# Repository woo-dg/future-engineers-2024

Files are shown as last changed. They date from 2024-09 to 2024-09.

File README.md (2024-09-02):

WRO Future Engineers Team SD Engineering Documentation
====

This repository contains engineering materials of a self-driven vehicle model participating in the WRO Future Engineers competition in the 2023 season. More information on each subcomponent of the robot is placed in the README.md files in each folder.

## Content
* `build` contains documentation about our chassis and material choice
* `electrical` contains schematic diagrams demonstrating the connections between different electromechanical components. It also includes the available datasheets for the aforementioned components, and it also has a markdown file explaining the reasoning for each component.
* `photos` contains two folders where one contains the team photos and the other contains the robot photos
* `src` contains the code of control software for all components that were programmed to participate in the competition
* `strategy` contains documentation and diagrams explaining our approach to the problem
* `video` contains the video.md file with the link to a video where the driving demonstration exists

## Rubric Requirements
* `Mobility Management` is found in `build` and  `electrical` 
* `Power and Sense Management` is found in `electrical`
* `Obstacle Management` is found in `strategy` and `src`
* `Pictures - Team and Vehicle` is found in `photos`
* `Performance Videos` is found in `video`
* `Engineering Factor` is found in `build` and `README`

### Who We Are
Team SD consits of 2 of high school students who aim to be leaders in the future of autonomous vehicles. By taking the initiative to take part in the WRO Future Engineers challenge, we hope to gain experience in this field of engineering and problem-solving. We have been exposed to many robotic and logical challenges through Zebra Robotics, where we participated in many problems, such as WRO Robomissions, FIRST LEGO League, and VEX Robotics Competition. Our goals for this season are the following:
- Gain knowledge in the field of autonomous vehicles
- Expose ourselves to the nuances of software organization (i.e. Github)
- Become proficient in the skills regarding electronic components
- Learn how to coordinate and work as a team to solve the problem with innovation and creativity

### Our Robot & Iterations
Our team has designed a four-wheel rear-driver autonomous vehicle to complete the 2024 WRO Future Engineers challenge. When making our robot, we wanted to be able to rapidly iterate and make changes whenever they were needed. To accomplish this, our chassis and frame are designed on SolidWorks and Fusion 360 CAD Software and were printed using PLA filament on Anycubic Kobra 2 3D printers. Our current robot is a small and compact vehicle causing it to be highly maneuverable, allowing us to avoid obstacles effortlessly. This vehicle is powered by 160rpm 12V Gear Box DC motors, allowing us to keep a compact and lightweight robot. To steer this chassis, we are using the MG90 Arduino Servo, which has an ample amount of torque and strength. This allows us to make sharp turns whenever needed.
Prior to making this robot, our team went through various different iterations and prototypes where we learnt many lessons about what our optimal robot should consist of. These lessons are the following:
- Be small and compact
- Effectively use sensors to identify our location and our ideal path
- Speed is not the first priority for this challenges
- Maneuverability is key to solving the obstacle challenge

One of these was a larger robot with the usage of many more sensors and parts. However, its large nature caused it to be difficult to maneuver and control. All of our efforts were in vain as we faced many hardships and problems when trying to program that robot. Our robot’s turning radius was too large, and it was unable to maneuver around the obstacles while our sensors were placed inconveniently and were unable to correctly and quickly construct an efficient path for our robot to take. We realized that many parts of our robot were unnecessary, especially the sheer size of it, and therefore we decided to do a complete redesign which led to our final robot design. A summary of the reasons for our redesign can be found below:

| | Pros | Cons |
| - | ---| ---|
| Old Robot | <ul><li>Allows for the attachment of larger sensors</li><li>Faster robot due to the larger, more powerful motors</li></ul> | <ul><li>Bad maneuverability due to size, causing a larger turning radius</li><li>Excessive use of unnecessary sensors</li><li>Not enough ports due to the sheer number of sensors</li></ul> |
| New Robot | <ul><li>Smaller and more compact</li><li>Better maneuverability and sharper turning radius</li><li>More effective use of sensors and gets rid of any unnecessary parts</li></ul> | <ul><li>Slower speed due to less powerful motors</li><li>Restrictions to the size of sensors and parts we can use</li></ul> |

### Electrical Components
Our chassis is controlled by the Arduino Nano microcontroller, which gets information from various sensors and uses said information to control the motors using an L298N motor controller board. The sensors that we are using for our vehicle are the following:

- Pixycam 2.1
- TCS34725 RGB Sensor
- GP2Y0A02YK0F IR Range Sensor (x 2)
- L3G4200D 3-Axis Gyro

We use the Pixycam 2.1 to identify the locations of the obstacles and effectively avoid them. The TCS34725 RGB sensor tells the microcontroller when it reaches a corner. Both IR sensors are used to detect the walls on the side and on the front. Finally, we use the L3G4200D gyro to know which direction we are facing. More information about our robot’s electrical components can be found in the README file in the electrical folder.

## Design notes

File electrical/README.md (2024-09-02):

Electrical
====

This directory consists of schematic diagrams demonstrating the connections between different components as well as datasheets for the components. It also consists of the reasoning behind the choice of components.

## Parts Explanation

| Part Name | Explanation | Image | Datasheet |
| --- | --- | --- | --- |
| 1.5V Rechargeable Lithium Ion Battery | We are using this battery to power all of our electronics as it is compact and easy to get. They are also efficient for us as they are rechargeable and do not have to be replaced. |  | [Battery Info](https://drive.google.com/file/d/1sINeE1pQsb4mYleB1K3RjQIi_3ilcRdc/view?usp=sharing) |
| DC 6V 25SG-2418BL 160RPM | We are using this specific motor to drive the robot as it contains a gearbox that can reach a maximum speed of 160RPM. The compact size of these motors, coupled with a high RPM, allowed for our smaller compact design to succeed. |  | [DC Motor Info](https://drive.google.com/file/d/1ovx4JvY0TAlGeaWuEGIg9i7RbAIlBQif/view?usp=drive_link) |
| CJMCU34725 TCS34725 RGB Light Color Sensor | By using this RGB color sensor, our robot can accurately detect the blue and orange lines at the mat's corners. This capability enables us to monitor the number of laps completed and ensures the robot makes precise turns when needed. |  | [Color Sensor Info](https://www.waveshare.com/w/upload/b/bb/TCS34725_Color_Sensor_user_manual_en.pdf) |
| Arduino Nano |To process sensor data and make real-time decisions, we are utilizing the Arduino Nano, programmed through the Arduino IDE. This board is user-friendly, with a wide range of readily available libraries. It features 14 digital input/output pins, allowing us to connect various devices, and eight analog pins, two of which are dedicated to I2C communication. | | [Arduino Nano Info](https://www.arduino.cc/en/uploads/Main/ArduinoNanoManual23.pdf) |
| ES08MA Metal Analog Servo | To steer our vehicle, we use a servo motor with a torque of 2.0 kilogram-force centimeters and a speed of 0.10 sec/60°. Given the substantial torque required for steering, this motor offers ample power for our needs. Additionally, its quick response time enables us to execute sharp turns with precision. |  | [Servo Info](https://m.media-amazon.com/images/I/61ZU3A84tYS._AC_SL1000_.jpg) |
| GP2Y0A02YK0F IR Range Sensor | The IR sensors deliver information about the distance to the walls at a fast rate. These sensors accurately detect distances ranging from 20 to 150 cm. We use one sensor to gauge how close the robot is to any wall in front, while the other two help the robot maintain a centered position on the track by following the walls on either side. |  | [GP2Y0A02YK0F IR Range Sensor Info](https://cdn.robotshop.com/media/d/dem/rb-dem-02/pdf/datasheet-gp2y0a02yk0f.pdf) |
| L3G4200D Triple Axis Gyro Angular Velocity Sensor Module |We use a gyro angular velocity sensor to determine our vehicle's angular direction and precisely measure the change in angle during each turn. For accurate angle measurements, we integrate the yaw angular velocity after calibrating the gyro, allowing us to determine the robot's angle relative to its starting position. |  | [Gyro Info](https://www.elecrow.com/download/L3G4200_AN3393.pdf) |
| PixyCam Pixy 2.1 Robot Vision Image Sensor | Since the Arduino Nano lacks sufficient computing power for image processing, we offload this task to the Pixy 2.1 camera. This camera efficiently provides the microcontroller with the necessary data, enabling the robot to plan and follow an optimal path. |  | [Pixy 2.1 Info](https://docs.pixycam.com/wiki/doku.php?id=wiki:v2:start) |

## Parts Bill Of Materials (BOM)
| Part Name | Quantity |
| ---| --- |
| 1.5V Rechargeable Lithium Ion Battery | 4 |
| DC 6V Micro Gear Box Speed Reduction Motor, 160RPM | 1 |
| CJMCU34725 TCS34725 RGB Light Color Sensor | 1 |
| Arduino Nano | 1 |
| ES08MA Metal Analog Servo | 1 |
| GP2Y0A02YK0F IR Range Sensor | 3 |
| L3G4200D Triple Axis Gyro Angular Velocity Sensor Module | 1 |
| PixyCam Pixy 2.1 Robot Vision Image Sensor | 1 |

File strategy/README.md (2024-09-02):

Strategy
====

This directory consists of an explanation and diagrams of our strategy for both the open and obstacle rounds.

## Open Challenge Strategy

In the open challenge, the only variations to the field are the size of the interior walls. To adapt to these changes, we employ IR distance sensors to measure the distance from the walls. With multiple sensors, the robot can accurately calculate its distance from the surrounding walls, enabling it to correct its course and maintain a parallel trajectory. The robot will know when to turn when the RGB sensor detects the colored lines at the corners. This also allows us to track the number of laps completed, ensuring we know when to finish. 

| Straight Movement | Turning |
| --- | --- |
|  |  |

| Open Challenge Flowchart |
| ------------------------ |
|  |

## Obstacle Challenge Strategy

Our strategy for the obstacle challenge is to maintain the closest detected color on the designated side of the robot. This is achieved by monitoring the x-position of objects identified by the camera and adjusting the steering accordingly to ensure that the object remains on the correct side. The turning and stopping mechanisms will utilize the same logic that was successfully implemented in the open challenge.

To optimize our steering adjustments, we employ a proportional control loop, which will allow for precise maneuvering as the robot encounters obstacles. This approach ensures that our movements are both accurate and responsive to the environment.

| Obstacle Challenge Simple Approach |
| ---------------------------------- |
|  |

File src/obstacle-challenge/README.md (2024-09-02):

## Obstacle Challenge Code Explanation

For our obstacle challenge, we use a combination of sensors, including an RGB sensor, IR sensors, a gyro sensor, and a Pixy2 camera. These sensors help the robot navigate the course, avoid obstacles, and execute precise turns. Our code is divided into two main parts: normal navigation and obstacle detection logic. Additionally, we have parking logic to ensure the robot parks correctly within the boundaries.

## Normal Navigation: 
The robot starts by using the RGB sensor, IR sensors, and gyro to maintain a straight path and avoid obstacles. The Pixy2 camera identifies objects and assists with steering adjustments. The Pixy2 camera detects blocks in the robot’s path. If a block is close enough (i.e., its y-coordinate is greater than 35), the robot stores this block as the current target:

`if (pixy.ccc.numBlocks) {
    sig = pixy.ccc.blocks[0].m_signature;
    x = pixy.ccc.blocks[0].m_x;
    y = pixy.ccc.blocks[0].m_y;
    if (sig == 1 && !p) {
        dG = 0;
        if (y > 35) {
            t = millis();
            pr = 1;
            if (x > 70) {
                dR = 75;
            }
        } else if (x < 70) {
            dR = 0;
        }
    }
}` . 

Based on the block’s position and color, the robot adjusts its steering to follow the block closely. This helps the robot maintain a path that avoids obstacles and keeps it on course.

## Wall Following:
When no blocks are detected or when the robot needs to avoid obstacles on its sides, it uses IR sensors for wall following. The robot measures the distance to the walls on its left and right and adjusts its course accordingly:
`if (bl) {
    if (distL < 30 && distR > 30) {
        dD = 30;
    } else if (distR < 30 && distL > 30) {
        dD = -30;
    } else {
        dD = 0;
    }
} else if (o) {
    if (distR < 30 && distL > 30) {
        dD = 20;
    } else if (distL < 30 and distR > 30) {
        dD = -20;
    } else {
        dD = 0;
    }
}` . 

The robot also checks for obstacles directly in front. If it detects something too close, it stops and backs up slightly before continuing. This prevents crashes and allows the robot to navigate around unexpected obstacles.

## Turning Logic 
When the robot approaches a corner and detects the designated color (either orange or blue), it moves forward until it sees the wall. Once the wall is detected and the color is still in view, the robot begins its turning maneuver using the gyro sensor to ensure a precise turn:
`dA += 89;
myservo.write(35);
move_str(false, 100, 1600);
myservo.write(85);`. 

The robot carefully checks its surroundings and only turns after confirming both the presence of the wall and the designated color. This helps the robot avoid premature turns and ensures that it follows the intended path accurately.

If the robot reaches a point where it needs to make a 180-degree turn (reverse lap), it uses the gyro to rotate until it’s aligned with the new direction:
`
dA = -783;
bl = true;
o = false;`

This code adjusts the robot’s internal angle tracking, ensuring it’s ready to continue in the opposite direction after the turn.

## Parking Logic:
After completing three laps, the robot enters the parking phase. It uses the Pixy2 camera to detect nearby objects and adjust its final position. Depending on whether it's in left or right mode, the robot makes slight adjustments to its steering based on the detected signature. If it sees a close block, it fine-tunes its position by setting the servo to a specific angle—either 50 or 120 degrees—depending on the direction. The robot then stops the motor, pauses briefly, and powers up slightly to hold its position, finally entering a prolonged delay to ensure it stays parked securely within the boundaries.
`   else if (p== true){
    if (bl == true){
      if (sig == 1||sig == 2){
        dR =75;
      }
      else if (sig == 3){
        if (y>65){
          myservo.write(50);
          analogWrite(mlp,0);
          digitalWrite(mld,true);
          delay(500);
          analogWrite(mlp,255);
          delay(1000000);
        }
      }
    }
    if (o == true){
      if (sig == 1||sig == 2){
        dG =75;
      }
      else if (sig == 3){
        if (y>65){
          myservo.write(120);
          analogWrite(mlp,0);
          digitalWrite(mld,true);
          delay(500);
          analogWrite(mlp,255);
          delay(1000000);
        }
      }
    }
  }
`.

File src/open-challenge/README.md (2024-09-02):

## Open Challenge Code

In our open challenge approach, we focus on utilizing gyro and infrared (IR) sensors to maintain a precise navigation path. The robot continuously reads sensor data to make real-time adjustments, ensuring it stays on course.

## Gyro-Based Steering:
Before the robot reaches the first corner, it relies on the gyro sensor to maintain a straight path, as it doesn't yet have a fixed directional reference. The robot computes the steering adjustment by mapping the difference between the current angle and the desired target angle:
`str = map(mpu.getAngleZ() - dA, 30, -30, 40, 130);
if (str > 130) {
    str = 130;
} else if (str < 40) {
    str = 40;
}
myservo.write(str);  // Adjust steering` . 

This code continuously updates the servo position, ensuring that the robot corrects any drift from its intended path by adjusting the steering angle.

## Color-Based Direction Setting:
As the robot navigates, it needs to establish and maintain its direction. We use an RGB color sensor to detect specific colors on the track, which helps the robot determine its heading. If the direction isn't set, it assigns the current color as the reference:

`if (lux < 6 && r < 10) {
    if (o == false) {
        dA = dA + 90;
        bl = true;
        bc++;
        while (mpu.getAngleZ() < dA - 15) {
            mpu.update();
            myservo.write(115);
            analogWrite(mlp, 0);
            digitalWrite(mld, true);
        }
    }
}` . 

This ensures the robot is aligned with the track's color cues, setting a baseline for subsequent maneuvers.

## Corner Detection and Handling:
The robot’s cornering logic activates when it detects a change in color, indicating a corner or junction. The system checks if the color matches the established direction and if sufficient time has passed since the last turn. If these conditions are met, the robot adjusts its target angle and prepares to execute a turn:
`if (lux < 6 && r > 15) {
    if (bl == false) {
        dA = dA - 90;
        o = true;
        oc++;
        while (mpu.getAngleZ() > dA + 15) {
            mpu.update();
            myservo.write(55);
            analogWrite(mlp, 0);
            digitalWrite(mld, true);
        }
    }
}`. 

This code allows the robot to make precise turns based on real-time sensor data, ensuring it navigates corners accurately.

## Wall Following:
In tight corridors or when close to walls, the robot employs a wall-following algorithm to maintain a safe distance. The IR sensors measure the distance to the nearest wall, and if the robot gets too close, it adjusts its course to steer away:
`if (bl) {
    mpu.update();
    str = map(mpu.getAngleZ() - dA, 30, -30, 40, 130);
    myservo.write(str);
    distR = sensorR.distance();
    if (distR > 35) {
        myservo.write(75);
    } else if (distR < 25) {
        myservo.write(95);
    }
}
`. 

This block ensures that the robot maintains an optimal distance from the wall by making fine adjustments to its steering, thus avoiding collisions.

## Final Control Adjustments:
Throughout its run, the robot continuously monitors its surroundings and adjusts both its steering and speed to stay on track. The system is designed to avoid abrupt movements, maintaining smooth and controlled navigation until it reaches the end of its path.

By integrating gyro stabilization, color-based direction setting, corner detection, and wall following, the robot effectively navigates the course with precision and adaptability, responding dynamically to its environment.

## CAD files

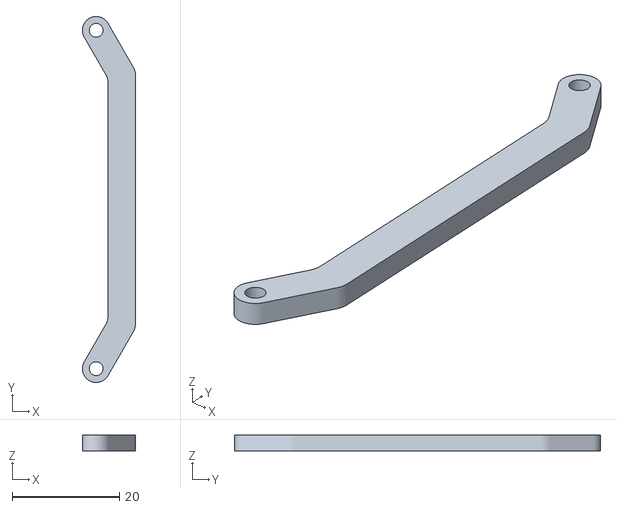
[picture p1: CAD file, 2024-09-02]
build/models/steer-shaft.stl
9.95 x 68.4 x 2.90

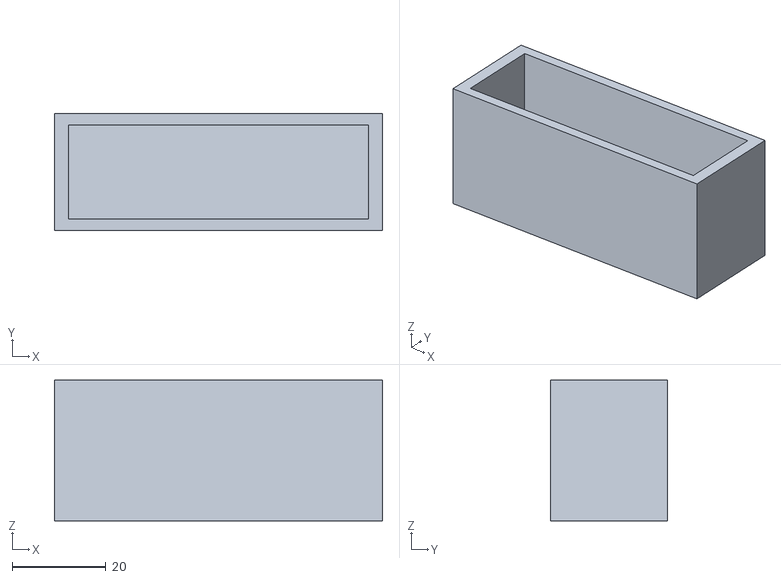
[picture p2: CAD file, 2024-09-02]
build/models/battery-holder.stl
70.0 x 25.0 x 30.0

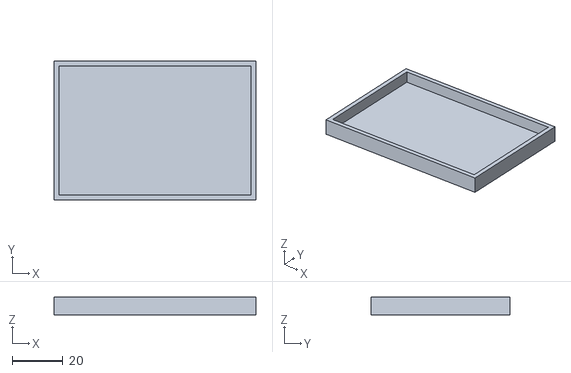
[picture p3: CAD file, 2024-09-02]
build/models/circuit-holder.stl
80.0 x 55.0 x 7.00

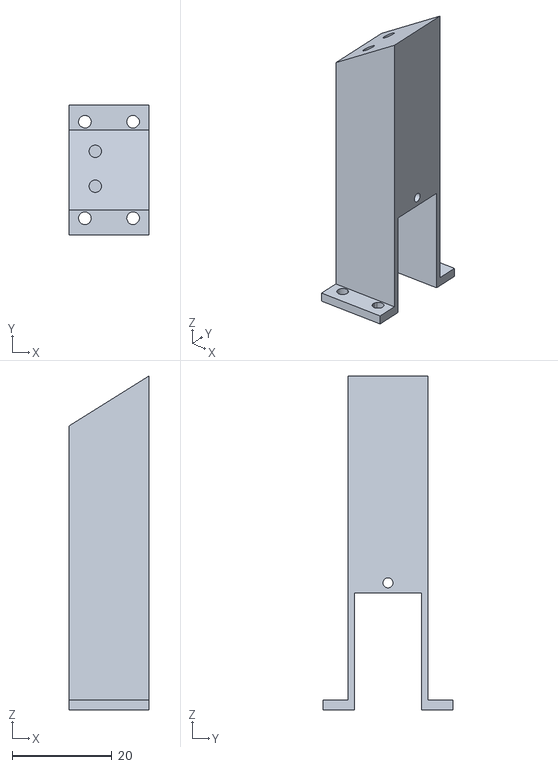
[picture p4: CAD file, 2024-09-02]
build/models/servo (1).stl
16.0 x 26.0 x 67.0

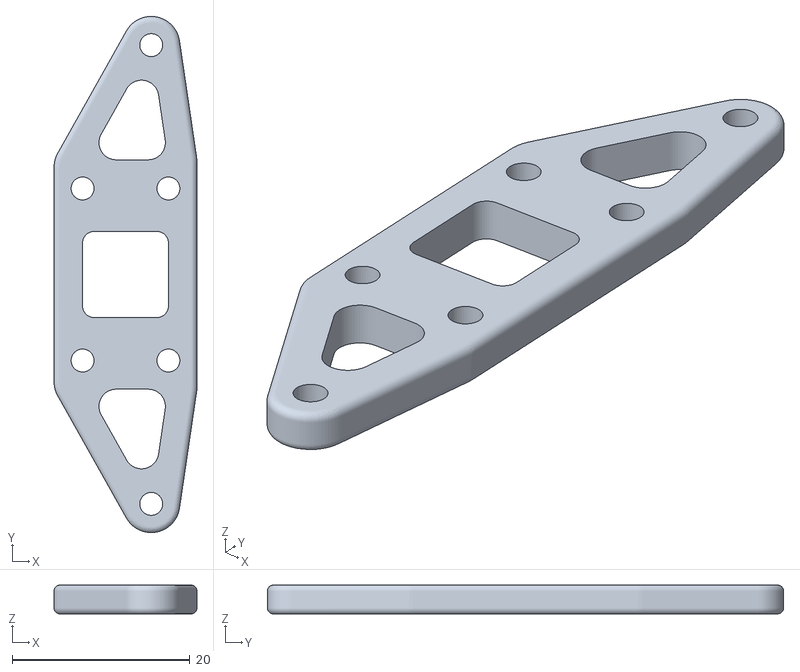
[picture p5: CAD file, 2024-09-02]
build/models/steering-plate.stl
16.1 x 58.1 x 3.23

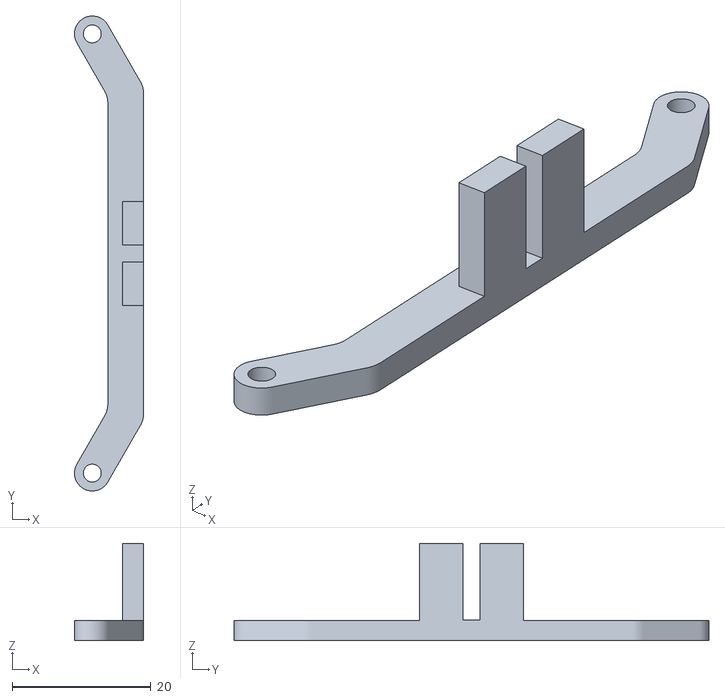
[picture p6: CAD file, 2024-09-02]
build/models/shaft.stl
9.95 x 68.4 x 14.0

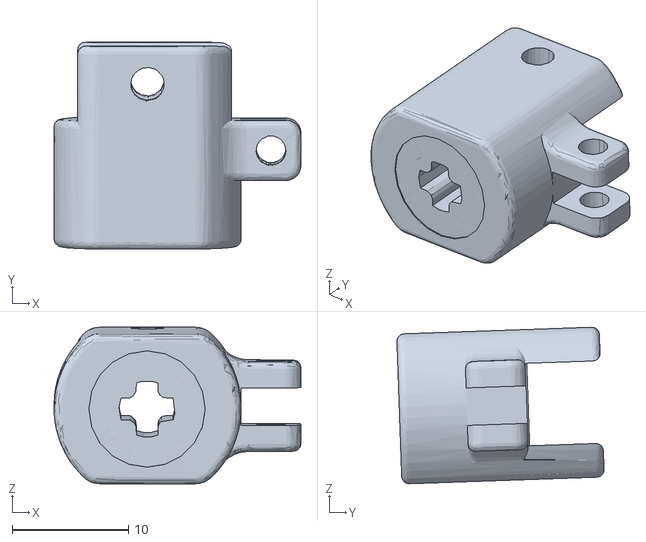
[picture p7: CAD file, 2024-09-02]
build/models/wheel-mount.stl
21.2 x 17.8 x 13.5

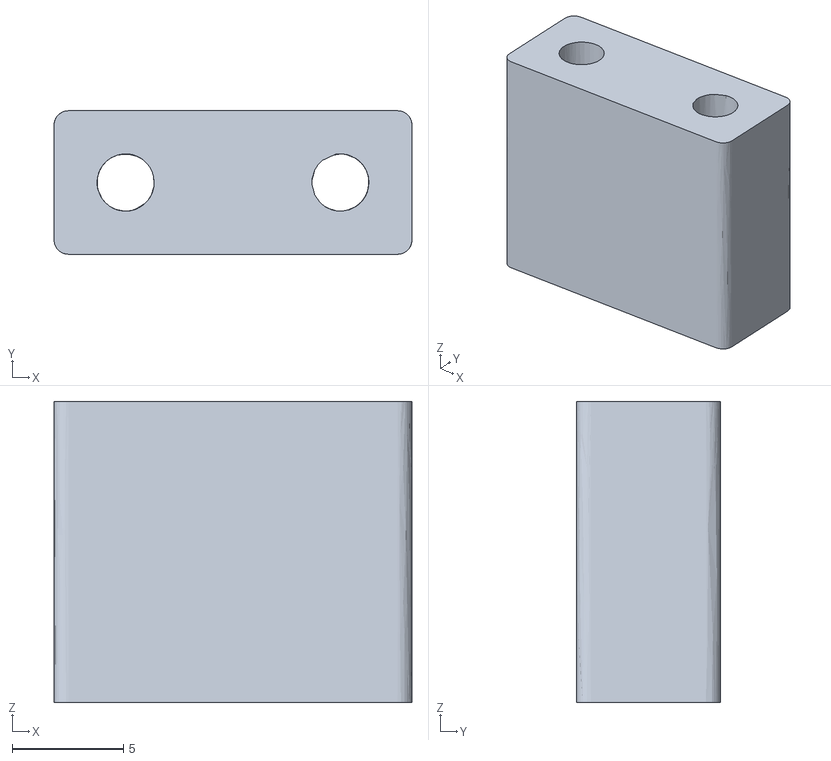
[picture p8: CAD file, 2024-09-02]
build/models/steering-holder.stl
16.1 x 6.45 x 13.5

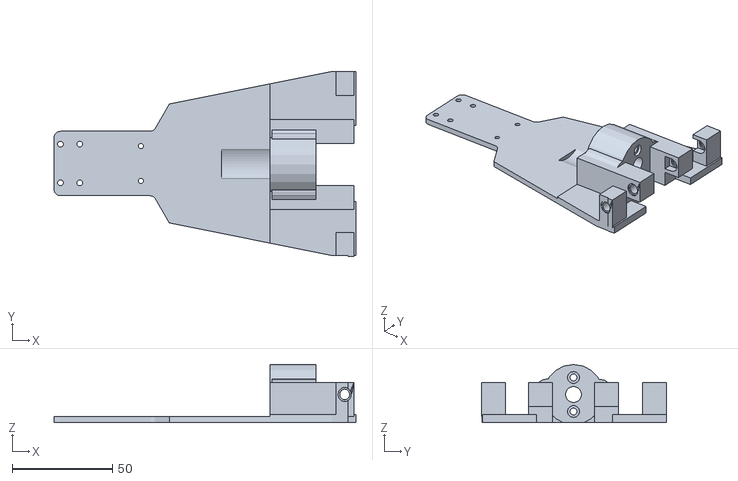
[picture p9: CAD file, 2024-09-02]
build/models/chassis.stl
151.0 x 92.5 x 29.0

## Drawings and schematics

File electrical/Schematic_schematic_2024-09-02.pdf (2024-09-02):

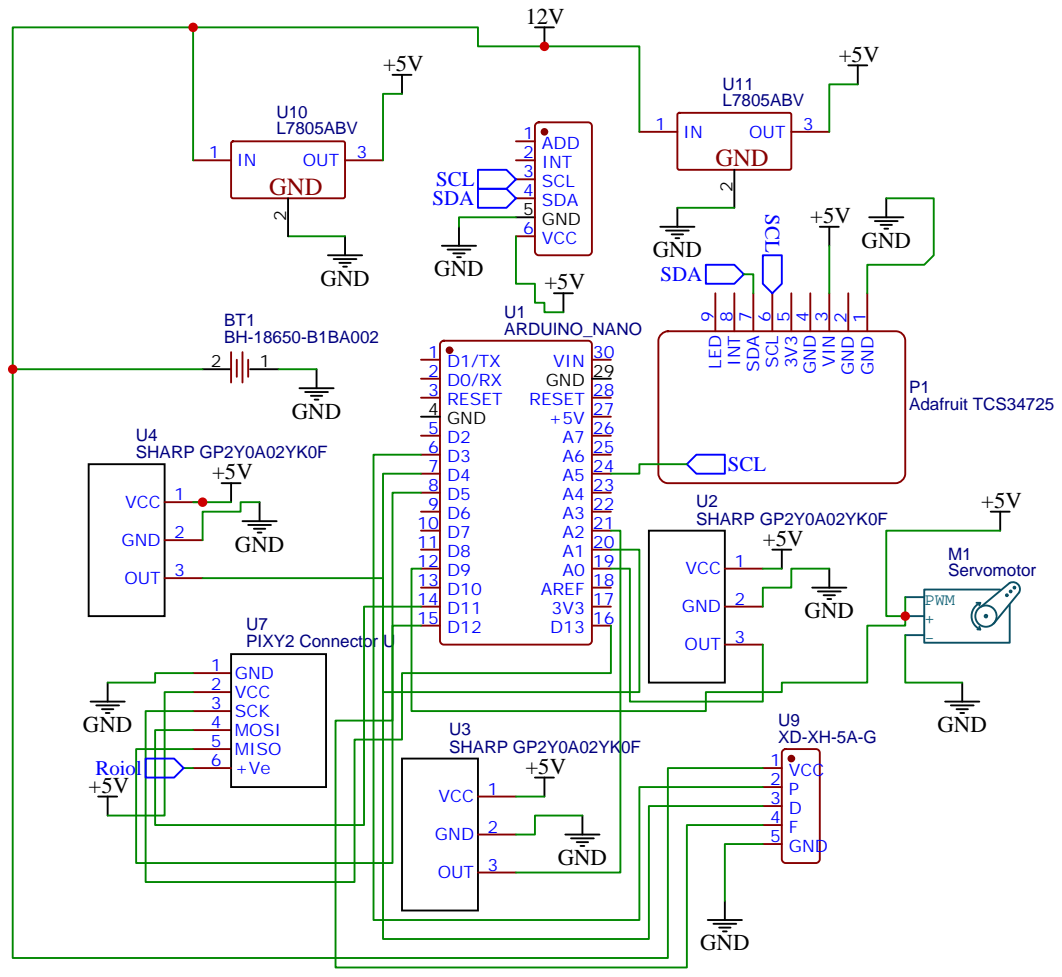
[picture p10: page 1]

Drawn By: Dave & Shourya

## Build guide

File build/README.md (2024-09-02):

Build
====

This directory consists of the different materials used to construct our robot, along with the reasoning for choosing our drivetrain. 

## Chassis Type & Explanation

We opted for a straightforward chassis design, prioritizing simplicity to minimize complexity and reduce the potential for mechanical failures. After consideration, we chose a drivetrain with rear-wheel drive coupled with front-wheel steering. This decision was based on our experience with similar rear-wheel-driven LEGO robots, making the control of our robot more familiar.

Utilizing all four wheels proved advantageous, particularly in maintaining a small turning radius, which is important for maneuverability in tight spaces. Additionally, we designed the wheelbase-to-track ratio to be 1:1.6. This specific ratio was selected to optimize stability, ensuring that our robot maintains a controlled movement even during sharp turns and complex maneuvers. 

| Rear-Wheel Drive |
| ---------------- |
|  |

## Steering

Our steering mechanism employs Ackerman steering geometry, where the servo motor adjusts the bar, altering the wheel angles and, consequently, the vehicle's direction. This type of steering proved to be the most efficient for our needs and was straightforward to implement, requiring only a servo motor and a simple linkage that connects the servo to the wheel axles. This design choice not only enhanced maneuverability but also simplified the overall construction process.

| Steering Mechanism |
| --------------------------- |
|  |

## Materials

When creating our robot, we aimed to easily iterate and update the design as we tested it. To achieve this flexibility, we CAD-designed several different versions of the same parts, allowing us to test and determine which were the most effective and properly optimized for the overall design of the robot. This approach helped us identify the optimal configuration for our robot's performance.

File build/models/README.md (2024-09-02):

Models
====

| File Name | Description |
| --- | --- |
| battery-holder.stl | We positioned our battery within this design to optimize weight distribution, contributing to the overall balance and stability of the robot.
| circuit-holder.stl | We securely housed our circuit in this holder to ensure it remains protected and stable, minimizing the risk of wires touching or becoming disconnected, which could lead to performance issues during the competition.
| servo.stl |We mounted both our servo and Pixy camera on the same attachment for two key reasons. First, the servo motor needed to be positioned at the front of the robot to effectively control the steering mechanism. Second, this attachment offered the ideal height and placement for the Pixy camera, ensuring it has the best field of view for accurate object detection. |
| shaft.stl, steer-shaft.stl, steering-holder.stl, steering-plate.stl, wheel-mount.stl | These CAD files contain the complete design of our steering mechanism. |

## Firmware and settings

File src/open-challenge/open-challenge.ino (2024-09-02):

#include <Servo.h>
#include <Wire.h>
#include "Adafruit_TCS34725.h"
#include <MPU6050_light.h>
#include "SharpIR.h"

// Define model and input pin:
#define model 1080
const int buttonPin = 5;  // Pin for the button

MPU6050 mpu(Wire);  // Initialize MPU6050 sensor
unsigned long timer = 0;  // Timer for MPU6050 updates

// Variables for different sensor readings and control states
int dA = 0;
int bc = 0;
int str = 0;
int oc = 0;
int distR = 0;
int distL = 0;
bool o = false;
bool bl = false;

Servo myservo;  // Create Servo object to control a servo

// Initialize TCS34725 color sensor with specific integration time and gain
Adafruit_TCS34725 tcs = Adafruit_TCS34725(TCS34725_INTEGRATIONTIME_2_4MS, TCS34725_GAIN_1X);

int pos = 90;  // Variable to store the servo position
int left_tick = 0;  // Counter for left wheel encoder ticks
bool left_flag = HIGH;  // Direction flag for left wheel

// Define motor control pins
#define mlp 3
#define mld 4   // Motor port 3
#define mlf 2

// Initialize Sharp IR sensors for distance measurement
SharpIR sensorR(A2, 20150);
SharpIR sensorL(A0, 20150);

void setup() {
  Serial.begin(9600);
  Wire.begin();
  
  // Initialize MPU6050 and calculate offsets
  byte status = mpu.begin();
  Serial.print(F("MPU6050 status: "));
  Serial.println(status);
  while (status != 0) {
    // Stop everything if the MPU6050 could not connect
  }
  Serial.println(F("Calculating offsets, do not move MPU6050"));
  delay(1000);
  mpu.calcOffsets();  // Calculate MPU6050 offsets
  
  // Initialize TCS34725 color sensor
  if (tcs.begin()) {
    Serial.println("Found sensor");
  } else {
    Serial.println("No TCS34725 found ... check your connections");
    while (1);
  }

  // Initialize servo and motor control pins
  myservo.attach(9);
  myservo.write(85);
  pinMode(mlp, OUTPUT);
  pinMode(mld, OUTPUT);
  attachInterrupt(digitalPinToInterrupt(mlf), left_wheel_pulse, RISING);

  // Setup button pin and wait for button press
  pinMode(buttonPin, INPUT);
  digitalWrite(buttonPin, HIGH);
  int buttonState = digitalRead(buttonPin);
  while (buttonState == 1) {
    buttonState = digitalRead(buttonPin);
  }
  delay(200);
}

void loop(void) {
  uint16_t r, g, b, c, colorTemp, lux;

  // Read raw color data from the TCS34725 sensor
  tcs.getRawData(&r, &g, &b, &c);
  mpu.update();  // Update MPU6050 sensor readings
  
  // Measure distances using the Sharp IR sensors
  distR = sensorR.distance();
  Serial.print("DistR: ");
  Serial.print(distR);
  
  distL = sensorL.distance();
  Serial.print("DistL: ");
  Serial.println(distL);
  
  // Calculate color temperature and lux
  colorTemp = tcs.calculateColorTemperature_dn40(r, g, b, c);
  lux = tcs.calculateLux(r, g, b);
  
  // Map the Z-axis angle to a steering angle and adjust if necessary
  str = map(mpu.getAngleZ() - dA, 30, -30, 40, 130);
  if (str > 130) {
    str = 130;
  } else if (str < 40) {
    str = 40;
  }
  myservo.write(str);  // Control the servo for steering
  
  // Stop the motor temporarily
  analogWrite(mlp, 0);
  digitalWrite(mld, true);
  
  // Logic for handling obstacle detection and avoidance based on lux and color readings
  if (lux < 6 && r < 10) {
    if (o == false) {
      dA = dA + 90;
      bl = true;
      bc++;
      while (mpu.getAngleZ() < dA - 15) {
        mpu.update();
        myservo.write(115);
        analogWrite(mlp, 0);
        digitalWrite(mld, true);
      }
    }
  }
  
  if (lux < 6 && r > 15) {
    if (bl == false) {
      dA = dA - 90;
      o = true;
      oc++;
      while (mpu.getAngleZ() > dA + 15) {
        mpu.update();
        myservo.write(55);
        analogWrite(mlp, 0);
        digitalWrite(mld, true);
      }
    }
  }
  
  // Adjust steering based on distance readings
  if (bl) {
    mpu.update();
    str = map(mpu.getAngleZ() - dA, 30, -30, 40, 130);
    myservo.write(str);
    distR = sensorR.distance();
    Serial.print("DistR: ");
    Serial.println(distR);
    
    if (distR > 35) {
      myservo.write(75);
    } else if (distR < 25) {
      myservo.write(95);
    }
  }
  
  if (o) {
    mpu.update();
    str = map(mpu.getAngleZ() - dA, 30, -30, 40, 130);
    myservo.write(str);
    distL = sensorL.distance();
    Serial.print("DistL: ");
    Serial.println(distL);
    
    if (distL > 35) {
      myservo.write(95);
    } else if (distL < 25) {
      myservo.write(75);
    }
  }
  
  // End loop if it has completed 3 laps
  if (oc == 12 || bc == 12) {
    move_degree(true, 50, 1600, 0);
    analogWrite(mlp, 255);
    digitalWrite(mld, false);
    delay(100000);  // Consider reducing or handling this delay differently
  }
}

// Function to move the robot a certain distance with a specific speed and steering angle
void move_degree(bool dir, int pace, float dis, int steer) {
  left_tick = 0;
  int str = map(steer, -100, 100, 35, 135);
  myservo.write(str);
  left_flag = dir;
  analogWrite(mlp, pace);
  digitalWrite(mld, left_flag);
  
  while (abs(left_tick) < dis * 0.75) {
    delayMicroseconds(1);
    Serial.println(left_tick);
  }
  
  analogWrite(mlp, 255);
  digitalWrite(mld, !left_flag);
  delay(10);
  left_tick = 0;
}

// Interrupt service routine for left wheel encoder pulse
void left_wheel_pulse() {
  if (left_flag) {
    left_tick++;
  } else {
    left_tick--;
  }
}

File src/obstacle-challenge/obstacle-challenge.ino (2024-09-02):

#include <MPU6050_light.h>
#include <Servo.h>
#include <Wire.h>
#include "Adafruit_TCS34725.h"
#include <Pixy2.h>
#include <SharpIR.h>

Pixy2 pixy;

// Define model and input pin
const int buttonPin = 5;
MPU6050 mpu(Wire);  // Initialize MPU6050 sensor
unsigned long t = 0;

// Variables for various sensor readings and control states
int dA = 0;
int str = 0;
int distR = 0;
int distL = 0;
int sig, x, y;
int dG = 0, dR = 0, dP = 0, dD = 0;
int pr = 0;
bool o = false;
bool bl = false;
bool p = false;
int bc = 0, oc = 0;
Servo myservo;  // Create Servo object to control a servo motor

// Initialize TCS34725 color sensor with specific integration time and gain
Adafruit_TCS34725 tcs = Adafruit_TCS34725(TCS34725_INTEGRATIONTIME_2_4MS, TCS34725_GAIN_4X);

int left_tick = 0;
bool left_flag = HIGH;

// Define motor control pins
#define mlp 3
#define mld 4
#define mlf 2

// Initialize Sharp IR sensors
SharpIR sensor1(A1, 20150);
SharpIR sensor2(A2, 20150);
SharpIR sensor3(A0, 20150);

void setup() {
  Serial.begin(9600);
  Wire.begin();
  
  // Initialize MPU6050 and calculate offsets
  byte status = mpu.begin();
  if (status != 0) {
    while (true) {}  // Stop if MPU6050 fails to initialize
  }
  mpu.calcOffsets();
  
  // Initialize color sensor
  if (!tcs.begin()) {
    Serial.println("No TCS34725 found ... check your connections");
    while (true) {}
  }
  
  // Initialize servo and motor control pins
  myservo.attach(9);
  myservo.write(85);
  pinMode(mlp, OUTPUT);
  pinMode(mld, OUTPUT);
  pixy.init();
  
  // Set up left wheel encoder interrupt
  attachInterrupt(digitalPinToInterrupt(mlf), left_wheel_pulse, RISING);

  // Wait for button press to start
  pinMode(buttonPin, INPUT);
  digitalWrite(buttonPin, HIGH);
  while (digitalRead(buttonPin) == 1) {}
  delay(1000);
}

void loop(void) {
  uint16_t r, g, b, c;
  tcs.getRawData(&r, &g, &b, &c);
  mpu.update();
  
  int distF = sensor1.distance();
  distR = sensor2.distance();
  distL = sensor3.distance();
  
  // Steering control based on gyro readings
  str = map(mpu.getAngleZ() - dA - dG + dR - dP + dD, 30, -30, 35, 135);
  str = constrain(str, 45, 125);
  myservo.write(str);
  analogWrite(mlp, 0);
  digitalWrite(mld, true);

  // Obstacle and color detection logic
  if (c < 10 && r < 15) {
    // Handle specific conditions for blue line detection and turning
    if (!o) {
      bl = true;
      bc++;
      while (true) {
        mpu.update();
        distF = sensor1.distance();
        if (distF < 25) {
          distR = sensor2.distance();
          analogWrite(mlp, 255);
          digitalWrite(mld, true);
          break;
        }
      }
      dA += 89;
      myservo.write(35);
      move_str(false, 100, 1600);
      myservo.write(85);
      if (sensor2.distance() > 35) {
        move_str(false, 0, 200);
      }
      move_str(true, 0, 200);
    }
  } else if (g > 1024 && b > 1024 && c < 100) {
    // Handle specific conditions for orange line detection and turning
    if (!bl) {
      o = true;
      oc++;
      while (true) {
        mpu.update();
        distF = sensor1.distance();
        if (distF < 25) {
          distL = sensor3.distance();
          analogWrite(mlp, 255);
          digitalWrite(mld, true);
          break;
        }
      }
      dA -= 88;
      myservo.write(130);
      move_str(false, 0, 1800);
      myservo.write(85);
      if (distL < 150) {
        move_str(true, 0, 400);
      }
      move_str(true, 0, 50);
    }
  }

  // Pixy2 block detection logic
  pixy.ccc.getBlocks();
  if (pixy.ccc.numBlocks) {
    sig = pixy.ccc.blocks[0].m_signature;
    x = pixy.ccc.blocks[0].m_x;
    y = pixy.ccc.blocks[0].m_y;
    
    // Handle different signatures detected by Pixy2
    if (sig == 1 && !p) {
      dG = 0;
      if (y > 35) {
        t = millis();
        pr = 1;
        if (x > 70) {
          dR = 75;
        }
      } else if (x < 70) {
        dR = 0;
      } else {
        dR = 0;
        e = 40;
      }
    } else if (sig == 2 && !p) {
      dR = 0;
      if (y > 75) {
        t = millis();
        pr = 2;
        if (x < 280) {
          dG = 75;
        }
      } else if (x > 280) {
        dG = 0;
      } else if (y > 200) {
        dG = 0;
      } else {
        dG = 0;
        e = 40;
      }
    } else if (sig == 3 && !p) {
      if (bl && y > 65 && x > 120) {
        dP = 75;
      } else if (x < 100) {
        dP = 0;
      }
      if (o && y > 65 && x > 150) {
        dP = -75;
      } else if (y > 200) {
        dP = 0;
      }
    }
  }

  // Wall detection and adjustment based on IR sensor readings
  distR = sensor2.distance();
  distL = sensor3.distance();
  if (bl) {
    if (distL < 30 && distR > 30) {
      dD = 30;
    } else if (distR < 30 && distL > 30) {
      dD = -30;
    } else {
      dD = 0;
    }
  } else if (o) {
    if (distR < 30 && distL > 30) {
      dD = 20;
    } else if (distL < 30 && distR > 30) {
      dD = -20;
    } else {
      dD = 0;
    }
  }

  // Handling turns and movement based on obstacle detection
  int rev = 8;
  if (oc == rev || bc == rev) {
    if (pr == 1 && o && oc == rev) {
      move_str(true, 0, 1400);
      myservo.write(130);
      move_str(false, 0, 2200);
      myservo.write(65);
      move_str(true, 0, 1300);
      dA = -8783;
      bl = true;
      o = false;
      oc++;
      bc = oc;
    } else if (pr == 1 && bl && bc == rev) {
      move_str(true, 0, 2000);
      myservo.write(40);
      move_str(false, 0, 2200);
      myservo.write(105);
      move_str(true, 0, 1300);
      dA = 783;
      o = true;
      bl = false;
      bc++;
      oc = bc;
    }
  }

  // Parking logic if necessary
  if (oc > 11 || bc > 11) {
    int tick = 0;
    while (tick++ < 1000) {
      mpu.update();
      str = map(mpu.getAngleZ() - dA, 30, -30, 35, 135);
      str = constrain(str, 40, 130);
      myservo.write(str);
      analogWrite(mlp, 0);
      digitalWrite(mld, true);
    }
    analogWrite(mlp, 255);
    digitalWrite(mld, true);
    delay(2000);
    p = true;
  }
}

// Function to move the robot straight for a certain distance
void move_str(bool dir, int pace, float dis) {
  left_tick = 0;
  left_flag = dir;
  analogWrite(mlp, pace);
  digitalWrite(mld, left_flag);
  while (abs(left_tick) < dis * 0.75) {
    mpu.update();
    delayMicroseconds(1);
  }
  analogWrite(mlp, 255);
  digitalWrite(mld, !left_flag);
  left_tick = 0;
}

// Interrupt service routine for left wheel encoder pulse
void left_wheel_pulse() {
  if (left_flag) {
    left_tick++;
  } else {
    left_tick--;
  }
}
